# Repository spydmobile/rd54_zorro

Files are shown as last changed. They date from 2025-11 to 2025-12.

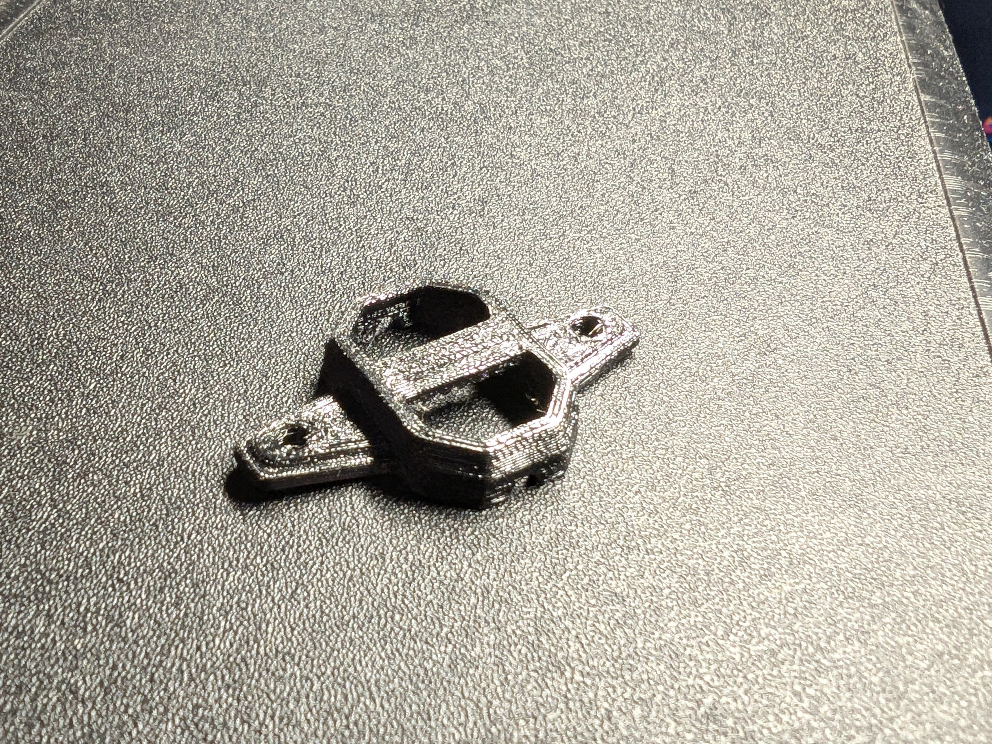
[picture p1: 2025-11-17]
custom_3d_printed_parts/RX mount/30.5 mm Receiver Holder (e.g. EP1, FlyFishRC VX3 style) - 7046298/images/PXL_20250523_1721312562.jpg

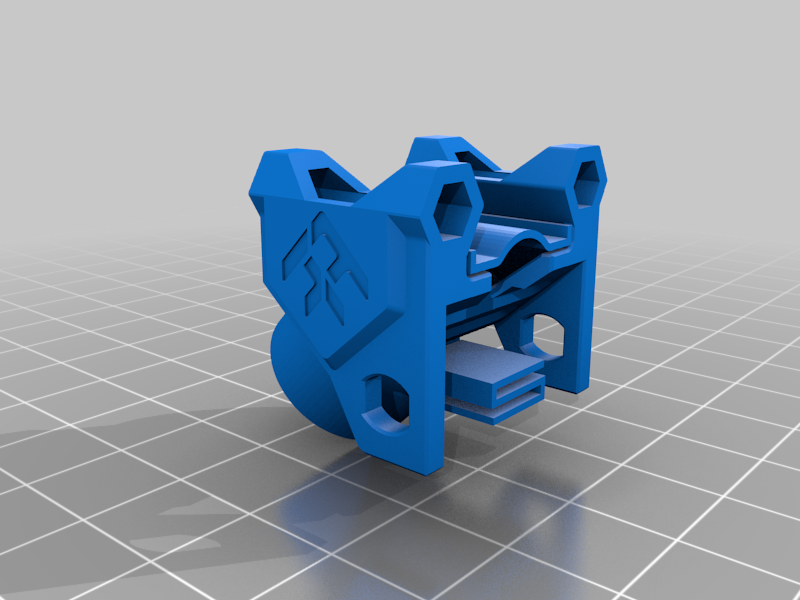
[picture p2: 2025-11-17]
custom_3d_printed_parts/factory_TPU_Parts/FlyFishRC Volador VX3 _ VX3.5 All-In-One TPU - 6052757/images/b86a3414-6690-473e-aafb-5c03349f377d.png

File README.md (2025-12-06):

# RD-54 "Zorro"

**Drone Designator**: RD-54
**Code Name**: Zorro
**Operator**: SpyD
**Platform**: 3.5" Digital FPV Cruiser

This repository serves as the source of truth for the RD-54 "Zorro" drone - a 3.5" digital FPV cruiser for exploration and cinematic HD video.

---

## Project Timeline

- **Parts Ordered**: Saturday, May 17, 2025 @ 8:56 AM
- **Build Commenced**: Monday, May 26, 2025 @ 4:33 PM
- **First Test Flight**: TBD
- **Status**: Assembly phase - VTX install + config remaining

---

## Current Configuration

- **Frame**: FlyFishRC Volador VX3.5
- **FC/ESC**: SpeedyBee F405 40A AIO (BlueJay)
- **Motors**: Emax ECO II 2004 3000KV (x4)
- **Video**: HDZero Freestyle V2 VTX + Camera
- **Antenna**: HDZero (rear mount)
- **Receiver**: HappyModel ExpressLRS EP1 Dual-TCXO
- **GPS**: GEPRC M10-DQ + VIFLY GPS-Mate
- **Batteries**: 2x GNB 880mAh 6S HV 160C (XT30)

---

## Documentation

Complete build documentation available in [`/Documentation`](/Documentation):

- **[As-Built Parts List](Documentation/RD-54_AsBuilt_Parts_List.md)** - Current aircraft configuration
- **[Build Timeline](Documentation/RD-54_Build_Timeline.md)** - Complete project history
- **[Incident Log](Documentation/RD-54_Incident_Log.md)** - Crash reports and maintenance
- **[Modifications Log](Documentation/RD-54_Modifications_Log.md)** - Engineering changes tracker

See [Documentation README](Documentation/README.md) for complete index.

---

## Quick Status

| Status | Value |
|---|---|
| Airworthy | No |
| Blocker | VTX install + Betaflight config |
| Total Flights | 0 |
| Total Incidents | 0 |

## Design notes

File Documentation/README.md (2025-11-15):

# RD-54 "Zorro" Documentation

**Aircraft Designator**: RD-54 (Code Name: Zorro)
**Operator**: SpyD (Franco Nogarin)
**Platform**: 3.5" Digital FPV Cruiser
**Primary Mission**: Exploration and cinematic FPV flights with HD digital video
**Last Updated**: November 14, 2025

---

## Quick Reference

### Current Status

| Attribute | Value |
|---|---|
| **Build Status** | Assembly Phase (~70% complete) |
| **Airworthiness** | Not Yet Airworthy (under construction) |
| **Flight Hours** | 0.0 |
| **Total Incidents** | 0 |
| **Total Modifications** | 1 (MOD-001: GPS Stack) |
| **Configuration** | Original Build Spec + GPS Stack Enhancement |
| **Mission Profile** | Digital FPV Cruiser |
| **Latest Milestone** | Motor wiring complete (Nov 14, 2025) |

### Key Specifications

| Component | Current Configuration |
|---|---|
| **Frame** | FlyFishRC Volador VX3.5 (3.5") |
| **FC/ESC** | SpeedyBee F405 AIO 40A (3-6S) |
| **Motors** | Emax ECO II 2004 3000KV |
| **Props** | Gemfan Hurricane 3525-3 Tri-Blade |
| **VTX** | Walksnail Moonlight HD digital (LHCP) |
| **RX** | HappyModel ExpressLRS EP1 (long range) |
| **GPS** | GEPRC M10-DQ with DPS310 baro |
| **GPS-Mate** | VIFLY GPS-Mate (lost model recovery) |
| **GPS Mount** | Custom 3D printed TPU stack (MOD-001) |
| **Battery** | 2x GNB 880mAh 6S HV 160C XT30 |

---

## Documentation Structure

### Primary Documentation

#### 1. [RD-54_AsBuilt_Parts_List.md](RD-54_AsBuilt_Parts_List.md)
**Single source of truth for current aircraft configuration**

Contains:
- Complete parts list with status
- Current operational configuration
- Pending upgrades
- Known issues
- Maintenance log

**Update when**: Parts are changed, issues discovered, maintenance performed

---

#### 2. [RD-54_Incident_Log.md](RD-54_Incident_Log.md)
**Comprehensive crash reports and damage assessments**

Contains:
- Chronological incident reports
- Damage assessments
- Root cause analysis
- Repair actions
- Lessons learned

**Update when**: Any crash, incident, or damage occurs

---

#### 3. [RD-54_Modifications_Log.md](RD-54_Modifications_Log.md)
**Track all engineering changes from original specification**

Contains:
- Sequential modification records (MOD-XXX)
- Original vs modified configuration
- Rationale and justification
- Installation procedures
- Performance impact

**Update when**: Planning, installing, or completing any modification

---

#### 4. [RD-54_Build_Timeline.md](RD-54_Build_Timeline.md)
**Chronological project history and future planning**

Contains:
- Build phases and milestones
- Project statistics
- Lessons learned
- Future activities

**Update when**: Major milestones reached, planning future work

---

### Reference Materials

#### [spyd.com_RD-54_README.md](spyd.com_RD-54_README.md)
Original parts list from spyd.com site. Reference only.

---

## How to Use This Documentation

### For Operators (SpyD)
1. **After a crash**: Document in `RD-54_Incident_Log.md`
2. **Ordering parts**: Update `RD-54_AsBuilt_Parts_List.md` (mark as "pending")
3. **Installing upgrades**: Create entry in `RD-54_Modifications_Log.md`
4. **After installation**: Update parts list status to "operational"
5. **Major milestones**: Update `RD-54_Build_Timeline.md`

### For Future Claude Instances
1. Read `CLAUDE.md` in repository root (your instructions)
2. Read this README (navigation guide)
3. Check `RD-54_AsBuilt_Parts_List.md` for current config
4. Review recent incident and modification entries
5. Ask operator what needs documenting

### For Documentation Maintenance
- Keep all cross-references current
- Update "Last Updated" dates
- Maintain chronological integrity
- Preserve historical records
- Follow markdown formatting standards

---

## Documentation Standards

### Markdown Formatting
- Tables for component lists and comparisons
- `---` dividers between major sections
- `**bold**` for component names and key terms
- `[ ]` checkboxes for pending actions
- Dates in ISO format (YYYY-MM-DD) or full format

### Technical Accuracy
- Full part numbers and model names
- Vendor names and order dates
- Quantities and prices when available
- Specific pad/connector names
- Units for all measurements (voltage, power, frequency)

### Documentation Voice
- Clear, technical language
- Assume FPV drone knowledge
- Document for future troubleshooting
- Include warnings and critical notes
- Capture operator's rationale

---

## Current Focus Areas

**Mission Profile**: Digital FPV Cruiser - optimized for smooth exploration flights with HD digital video

**Build Progress**: Assembly phase ~70% complete (started May 26, 2025)
- ✓ Frame assembled
- ✓ All motors mounted and wired (4 of 4 - completed Nov 14, 2025)
- ✓ FC/ESC stack installed and positioned
- ✓ Custom GPS stack fabricated and wired (MOD-001)
- ⏳ Remaining: Install VTX/Camera/RX/buzzer, mount GPS stack (last), wire management

**Next Steps**:
- Install Walksnail Moonlight VTX/Camera (next major task)
- Install ExpressLRS receiver
- Install buzzer
- Wire management and antenna routing
- Mount GPS stack to frame (planned as final component)
- Install top plate
- Betaflight configuration (GPS Rescue, RTH enabled)
- Bench testing
- Maiden flight

**Key Features for Cruiser Mission**:
- Walksnail HD digital FPV for cinematic footage
- GPS Rescue and Return Home for extended range safety
- VIFLY GPS-Mate for lost model recovery
- ExpressLRS long-range control link

**Documentation Priorities**:
- Document build progress and assembly milestones
- Capture configuration decisions for cruiser-optimized setup
- Record any issues encountered

---

## Contact & Support

**Operator**: SpyD (Franco Nogarin)
**Archivist**: Claude Code, RD-54 SME
**Repository**: /Users/franconogarin/localcode/rd54_zorro

---

## Document History

- **v1.0** (Nov 14, 2025): Initial documentation structure created
  - Created primary documentation files
  - Established templates and standards
  - Populated with current build information

---

**Next Review Date**: After first flight or major milestone

**Archivist**: Claude Code, RD-54 SME

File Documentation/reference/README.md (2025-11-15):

# Reference Materials

This directory contains **reference-only** documentation - original planning documents and historical specifications that should **NOT** be modified.

---

## Contents

### [spyd.com_RD-54_README.md](spyd.com_RD-54_README.md)
Original parts list from spyd.com site.

**Purpose**: Historical reference for original build specification
**Status**: Reference only - DO NOT MODIFY
**Date**: May 2025 (original build planning)

Contains:
- Original parts selection
- Baseline component specifications
- Initial build intent

---

## Usage Notes

### Reference Materials Are:
- ✓ Historical records
- ✓ Original planning documents
- ✓ Comparison baselines
- ✓ Preserved in original form

### Reference Materials Are NOT:
- ✗ Current configuration (see `RD-54_AsBuilt_Parts_List.md`)
- ✗ Living documents
- ✗ To be modified or updated
- ✗ Sources of truth for current specs

---

## For Current Configuration

**Always refer to the primary documentation**:
- Current specs: `../RD-54_AsBuilt_Parts_List.md`
- Modifications: `../RD-54_Modifications_Log.md`
- Incidents: `../RD-54_Incident_Log.md`
- Timeline: `../RD-54_Build_Timeline.md`

---

## Future Reference Documents

As the project evolves, additional reference materials may be added here:
- Original vendor invoices/receipts
- Initial planning notes
- Alternative build proposals
- Retired specifications

All reference materials should be clearly dated and marked as historical.

---

**Last Updated**: November 14, 2025
**Archivist**: Claude Code, RD-54 SME

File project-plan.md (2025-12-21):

# Project Plan: RD54 Zorro

**Project:** RD54_Zorro
**Owner:** Circuit (Fleet Steward)
**Created:** December 21, 2025
**Status:** Under Construction (~70%)

---

## Overview

RD54 "Zorro" is a 3.5" digital FPV cruiser optimized for smooth exploration with HD video. Features Walksnail digital system, GPS Rescue, and long-range ELRS.

**Repository:** `spydmobile/RD54_Zorro`
**Location:** `projects/drone_management/drones/RD54_Zorro/`
**Platform:** 3.5" Digital Cruiser (FlyFishRC Volador VX3.5)

---

## Current State

| Attribute | Value |
|---|---|
| **Build Status** | Assembly Phase (~70%) |
| **Airworthiness** | NOT YET AIRWORTHY |
| **Flight Hours** | 0.0 |
| **Total Incidents** | 0 |
| **Video System** | Walksnail Moonlight HD (LHCP) |
| **Control Link** | ExpressLRS EP1 (pending install) |
| **GPS** | GEPRC M10-DQ + VIFLY GPS-Mate |

**Completed:**
- Frame assembled
- All 4 motors mounted and wired (Nov 14, 2025)
- FC/ESC stack installed
- Custom GPS stack fabricated (MOD-001)

**Remaining:**
- VTX/Camera installation
- Receiver installation
- Buzzer installation
- Wire management
- GPS stack mounting (final step)
- Betaflight configuration
- Maiden flight

---

## Milestones

### Milestone 1: Frame & Motors (COMPLETE)
**Status:** Complete | **Date:** November 14, 2025

- [x] Frame assembly (Volador VX3.5)
- [x] FC/ESC stack positioning
- [x] Motor 1 mounting and wiring
- [x] Motor 2 mounting and wiring
- [x] Motor 3 mounting and wiring
- [x] Motor 4 mounting and wiring

### Milestone 2: GPS Stack (COMPLETE)
**Status:** Complete | **Date:** November 2025

- [x] Design custom TPU stack mount (MOD-001)
- [x] 3D print GPS mount
- [x] Wire GPS and GPS-Mate
- [x] Test fit on frame

### Milestone 3: Video System (IN PROGRESS)
**Status:** In Progress | **Priority:** High

- [x] Parts acquired (Walksnail Moonlight HD)
- [ ] Mount VTX to frame
- [ ] Install camera
- [ ] Route antenna (LHCP)
- [ ] Wire to FC

### Milestone 4: Receiver & Buzzer (PENDING)
**Status:** Pending | **Priority:** High

- [ ] Install ExpressLRS EP1 receiver
- [ ] Route RX antennas
- [ ] Install buzzer (5V)
- [ ] Wire management

### Milestone 5: GPS Final Mount (PENDING)
**Status:** Pending | **Priority:** Medium

Install GPS stack as final component (on top).

- [ ] Mount GPS stack to frame
- [ ] Antenna placement optimization
- [ ] Install top plate

### Milestone 6: Configuration & Testing (PENDING)
**Status:** Pending | **Priority:** High

- [ ] Betaflight configuration
- [ ] GPS Rescue setup
- [ ] RTH configuration
- [ ] Walksnail binding
- [ ] ELRS binding
- [ ] Bench test all systems
- [ ] Pre-flight safety checks
- [ ] First hover test
- [ ] Maiden FPV flight

---

## GitHub Issues

| # | Title | Labels | Priority |
|---|---|---|---|
| 1 | Install HDZero Freestyle V2 VTX/Camera System | pending-install, video-system | high |
| 3 | Install ExpressLRS EP1 Receiver and Antennas | pending-install, radio-system | high |
| 4 | Install GPS/GPS-Mate Stack | pending-install | - |
| 5 | Install HDZero Antenna Holder | pending-install, video-system | - |
| 6 | Install XT60 Battery Mount | pending-install | - |

*Note: Issue #1 references HDZero but drone uses Walksnail - verify correct VTX*

---

## Current Tasks

| Task | Priority | Status |
|---|---|---|
| Install Walksnail VTX/Camera | High | Next task |
| Install ELRS receiver | High | After VTX |
| Install buzzer | Medium | After RX |
| Wire management | Medium | After components |
| Mount GPS stack | Medium | Last component |
| Betaflight configuration | High | After assembly |
| Maiden flight | High | Final milestone |

---

## Operations

**Build documentation:**
- Parts List: `Documentation/RD-54_AsBuilt_Parts_List.md`
- Timeline: `Documentation/RD-54_Build_Timeline.md`
- Modifications: `Documentation/RD-54_Modifications_Log.md`

**Mission profile:** Digital FPV Cruiser
- Smooth exploration with HD video
- GPS Rescue for extended range safety
- Return-to-home capability

---

*Circuit - Fleet Steward*

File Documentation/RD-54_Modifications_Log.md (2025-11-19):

# RD-54 "Zorro" - Modifications Log

**Aircraft Designator**: RD-54 (Code Name: Zorro)
**Operator**: SpyD (Franco Nogarin)
**Last Updated**: November 15, 2025

---

## Purpose

This log tracks all engineering changes and modifications to RD-54 "Zorro" from the original build specification. Each modification receives a sequential MOD number.

---

## Modification Summary

| MOD # | Date | Category | Component | Status | Impact |
|---|---|---|---|---|---|
| MOD-001 | Nov 2025 | Enhancement | GPS/GPS-Mate Stack | Completed | Added VIFLY GPS-Mate, improved GPS elevation |
| MOD-002 | Nov 15, 2025 | Replacement | VTX System | In Progress | Changed from Walksnail Moonlight to HDZero Freestyle V2 |

**Total Modifications**: 2
**Current Configuration**: Original Build Spec + GPS Stack Enhancement + HDZero VTX

---

## Modification Categories

- **Emergency Repair**: Forced by damage/incident
- **Upgrade**: Performance or reliability improvement
- **Enhancement**: New capability addition
- **Replacement**: Like-for-like part swap

---

## Modifications

### MOD-001 - Custom 3D Printed GPS/GPS-Mate Stack

**Date Proposed**: November 2025
**Date Implemented**: November 2025
**Category**: Enhancement
**Status**: Completed (ready for installation)

#### Original Configuration

| Component | Part Number | Specification |
|---|---|---|
| GPS | GEPRC M10-DQ | GPS/GNSS with DPS310 baro, front mount elevated 8mm+ |
| GPS-Mate | N/A | Not included in original build |
| GPS Mount | N/A | Standard elevation mount |

#### Modified Configuration

| Component | Part Number | Specification |
|---|---|---|
| GPS | GEPRC M10-DQ | GPS/GNSS with DPS310 baro, mounted on custom stack |
| GPS-Mate | VIFLY GPS-Mate | Lost-model finder, integrated into stack |
| GPS Mount | Custom 3D Printed (TPU) | Modular vertical stack design |

#### Rationale

**Technical Justification**:
- Elevates GPS module higher for improved signal reception and reduced interference from carbon fiber frame
- Integrates VIFLY GPS-Mate lost-model finder for aircraft recovery capability
- Modular design allows easy servicing/replacement of individual components
- TPU material provides vibration damping and impact resistance

**Performance Impact**:
- Expected: Better GPS lock performance with increased elevation
- Expected: Aircraft recovery capability via GPS-Mate beacon
- Expected: Reduced vibration-induced GPS noise

**Operator Notes**:
Lost-model recovery is critical for a small 3.5" platform that could be difficult to visually locate. Custom integrated stack solution is more elegant than separate mounting solutions.

#### Parts Required

| Part | Vendor | Order Date | Cost | Status |
|---|---|---|---|---|
| VIFLY GPS-Mate | TBD | TBD | TBD | ✓ Acquired |
| TPU Filament | TBD | TBD | TBD | ✓ Used |
| Custom 3D Printed Parts | In-house design/print | Nov 2025 | Material cost only | ✓ Completed |

#### Implementation Notes

**Design Date**: November 2025
**Print Date**: November 2025
**Wiring Completed**: November 19, 2025
**Installation Status**: Ready for installation (not yet mounted to aircraft)
**Designed/Built By**: SpyD

**Design Features**:
- Yellow TPU construction for visibility and flexibility
- Modular vertical stack configuration
- GPS module on top ("ANTENNA THIS SIDE UP" orientation)
- VIFLY GPS-Mate in middle section
- Custom wiring harness fabricated (5-pin JST + 2 I2C solder wires)
- Integrated mounting points for frame installation

**Custom Wiring Harness** (Completed November 19, 2025):
- **5-pin JST Connector** (FC → GPS-Mate):
  - Black = GND
  - White = TX (from FC) → RX (to GPS-Mate)
  - Green = RX (from FC) → TX (to GPS-Mate)
  - Red = 5V
  - Yellow = BZ- (buzzer negative from FC to GPS-Mate built-in buzzer)
- **I2C Solder Connections**:
  - Drone SDA wire (white) → solder to GPS-Mate SDA wire (green)
  - Drone SCL wire (blue) → solder to GPS-Mate SCL wire (blue)

**Buzzer Integration**:
- GPS-Mate has integrated buzzer service
- FC buzzer pads wired to GPS-Mate BZ- (yellow wire in 5-pin JST)
- Provides all buzzer functions: arming, battery warnings, lost model beacon, etc.
- **No external buzzer needed** - GPS-Mate handles all buzzer functionality

**Installation Procedure**:
1. Mount GPS stack to frame (install last after other components)
2. Plug 5-pin JST connector from drone harness into GPS-Mate
3. Solder drone SDA wire (white) to GPS-Mate SDA wire (green)
4. Solder drone SCL wire (blue) to GPS-Mate SCL wire (blue)
5. Verify all connections secure and insulated
6. Configure GPS in Betaflight

**Notes**:
Assembly has been fabricated, wired, and tested off-aircraft. Drone-side harness complete. Ready to install when frame wiring phase continues. See reference photo: `Documentation/reference/build-images/GPS_Stack.jpg`

#### Post-Modification Performance

**Test Flight Date**: TBD (aircraft not yet airworthy)
**Test Results**: TBD

**Expected vs Actual**: TBD after flight testing

#### Related Documents

- Incident: N/A
- Timeline: Updated in RD-54_Build_Timeline.md
- Parts List: Updated in RD-54_AsBuilt_Parts_List.md
- Reference Photo: `Documentation/reference/build-images/GPS_Stack.jpg`

---

### MOD-002 - VTX System Technology Change (Walksnail → HDZero)

**Date Proposed**: November 15, 2025
**Date Implemented**: In Progress
**Category**: Replacement
**Status**: In Progress

#### Original Configuration

| Component | Part Number | Specification |
|---|---|---|
| VTX | Walksnail Moonlight | Digital HD VTX, large footprint kit, JST-SH 4-pin power, LHCP pigtails |
| Camera | Walksnail Moonlight Camera | Integrated with VTX kit |
| Antennas | LHCP (included with kit) | Left-hand circular polarization |

#### Modified Configuration

| Component | Part Number | Specification |
|---|---|---|
| VTX | HDZero Freestyle V2 | Digital HD VTX (specifications TBD) |
| Camera | HDZero Freestyle V2 Camera | Integrated with VTX |
| Antennas | TBD | TBD |

#### Rationale

**Technical Justification**:
- Both systems are digital HD - technology swap with similar capabilities
- HDZero Freestyle V2 became available from mapping mission
- Installation ramifications similar between both digital systems
- Allows RD-54 to proceed while RD-59 timeline shifted

**Performance Impact**:
- Expected: Similar HD digital video performance
- Expected: Comparable latency and range characteristics
- Expected: Similar installation footprint and wiring requirements

**Operator Notes**:
RD-59 project timeline changed and won't be airworthy for a while. HDZero Freestyle V2 showed up from yesterday's mapping mission, making it available for RD-54 instead. Since both are digital systems, the install approach should be comparable.

#### Parts Required

| Part | Vendor | Order Date | Cost | Status |
|---|---|---|---|---|
| HDZero Freestyle V2 VTX/Camera | From mapping mission | N/A | N/A | ✓ Available |
| Walksnail Moonlight (original) | - | May 17, 2025 | - | ⏳ Reassigned to other aircraft |

#### Installation Procedure

- [ ] Design and print any required camera/VTX mounts
- [ ] Mount HDZero Freestyle V2 VTX to frame
- [ ] Mount HDZero camera
- [ ] Wire VTX power to FC (verify voltage requirements)
- [ ] Wire VTX data connections (if applicable)
- [ ] Route antenna(s)
- [ ] Bench test video system
- [ ] Flight test video quality

#### Implementation Notes

**Installation Date**: TBD (in progress)
**Installed By**: SpyD

**Notes**:
Modification identified on November 15, 2025 after arm covers were completed. HDZero system will be installed after antenna mounts are designed/printed and ExpressLRS receiver is installed.

#### Post-Modification Performance

**Test Flight Date**: TBD
**Test Results**: TBD

**Expected vs Actual**: TBD

#### Related Documents

- Incident: N/A
- Timeline: Updated in RD-54_Build_Timeline.md (November 15, 2025)
- Parts List: Updated in RD-54_AsBuilt_Parts_List.md

---

## Modification Template

When documenting a modification, use this template:

### MOD-XXX - [Brief Description]

**Date Proposed**: [Date]
**Date Implemented**: [Date]
**Category**: [Emergency Repair / Upgrade / Enhancement / Replacement]
**Status**: [Proposed / In Progress / Completed / Abandoned]

#### Original Configuration

| Component | Part Number | Specification |
|---|---|---|
| | | |

#### Modified Configuration

| Component | Part Number | Specification |
|---|---|---|
| | | |

#### Rationale

**Technical Justification**:
[Why this modification is being made]

**Performance Impact**:
[Expected performance changes]

**Operator Notes**:
[Operator's reasoning/decision factors]

#### Parts Required

| Part | Vendor | Order Date | Cost | Status |
|---|---|---|---|---|
| | | | | |

#### Installation Procedure

- [ ] [Step 1]
- [ ] [Step 2]
- [ ] [Bench test]
- [ ] [Flight test]

#### Implementation Notes

**Installation Date**: [Date]
**Installed By**: SpyD

**Notes**:
[Any installation observations]

#### Post-Modification Performance

**Test Flight Date**: [Date]
**Test Results**:
[Performance observations]

**Expected vs Actual**:
[Did it meet expectations?]

#### Related Documents

- Incident: [Link to incident if applicable]
- Timeline: [Link to timeline entry]
- Parts List: [Updated in RD-54_AsBuilt_Parts_List.md]

---

**Document Version**: 1.0
**Archivist**: Claude Code, RD-54 SME

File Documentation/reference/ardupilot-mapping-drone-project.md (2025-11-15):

# ArduPilot Mapping Drone with ELRS MAVLink Telemetry
## Cable-Free Ground Control Station Setup

**Project Goal:** Build a custom autonomous mapping drone using ArduPilot with wireless MAVLink telemetry over ExpressLRS, eliminating the need for separate telemetry radios or cables between transmitter and laptop.

**Primary Use Case:** Aerial mapping and surveying for forestry/wildfire management applications

---

## System Architecture Overview

```
┌─────────────────────────────────────────────────────────┐
│                      AIRCRAFT                            │
│                                                          │
│  ┌─────────────────────────────────────────────────┐   │
│  │ Flywoo GOKU H743 PRO Mini Stack                  │   │
│  │ - H743 Flight Controller                         │   │
│  │ - 45A AM32 ESC (integrated)                      │   │
│  │ - ArduPilot Firmware                             │   │
│  │ - MAVLink configured on UART                     │   │
│  └──────────────┬──────────────────────────────────┘   │
│                 │                                        │
│                 │ UART Connection                        │
│                 │                                        │
│  ┌──────────────▼──────────────────────────────────┐   │
│  │ iFlight ELRS 2.4GHz 500mW TX Module              │   │
│  │ (Flashed with RECEIVER firmware)                 │   │
│  │ - RX-as-TX mode (ELRS 3.5+)                      │   │
│  │ - 500mW uplink power                             │   │
│  │ - MAVLink protocol mode                          │   │
│  └─────────────────────────────────────────────────┘   │
│                                                          │
└──────────────────────────┬───────────────────────────────┘
                           │
                           │ RF Link (2.4GHz ELRS)
                           │ • RC Control (uplink)
                           │ • MAVLink Telemetry (bidirectional)
                           │
┌──────────────────────────▼───────────────────────────────┐
│                   GROUND STATION                          │
│                                                           │
│  ┌────────────────────────────────────────────────┐     │
│  │ RadioMaster Boxer Transmitter                   │     │
│  │                                                 │     │
│  │  ┌──────────────────────────────────────────┐ │     │
│  │  │ Ranger Micro 2.4GHz ELRS TX Module       │ │     │
│  │  │ - 1W output power                        │ │     │
│  │  │ - WiFi Backpack enabled                  │ │     │
│  │  │ - MAVLink mode                           │ │     │
│  │  │ - Creates WiFi AP                        │ │     │
│  │  └─────────────┬────────────────────────────┘ │     │
│  │                │                                │     │
│  │                │ WiFi UDP (MAVLink)             │     │
│  └────────────────┼────────────────────────────────┘     │
│                   │                                       │
│                   │ Wireless Connection                   │
│                   │ No cables!                            │
│  ┌────────────────▼────────────────────────────────┐    │
│  │ Laptop / Tablet                                  │    │
│  │ - Mission Planner / QGroundControl               │    │
│  │ - Connects to "ExpressLRS TX Backpack XXXXXX"   │    │
│  │ - UDP port 14550                                 │    │
│  └──────────────────────────────────────────────────┘    │
│                                                           │
└───────────────────────────────────────────────────────────┘
```

---

## Hardware Bill of Materials

### Aircraft Components

| Item | Model | Purpose | Price | Notes |
|---|---|---|---|---|
| **Flight Controller Stack** | Flywoo GOKU H743 PRO Mini 45A AM32 20x20 | Flight control + ESC | $114.99 | H743 processor, 20x20 mounting, integrated 45A ESC |
| **ELRS TX Module** | iFlight ELRS 2.4GHz 500mW TX | Telemetry (flashed as RX) | ~$42.00 | Will be flashed with receiver firmware using RX-as-TX feature |
| **GPS Module** | Standard ArduPilot-compatible GPS | Position/navigation | ~$30-80 | UBLOX M8N/M9N or better |
| **Frame** | Your choice | Airframe | Varies | Based on your mapping mission requirements |
| **Motors** | Your choice | Propulsion | Varies | Match to frame and battery |
| **Battery** | LiPo 4S-6S | Power | Varies | Based on flight time requirements |

### Ground Station Components

| Item | Model | Purpose | Price | Status |
|---|---|---|---|---|
| **Transmitter** | RadioMaster Boxer 4-in-1 | RC control | - | ✅ You own this |
| **ELRS TX Module** | Ranger Micro 2.4GHz ELRS | 1W transmitter with WiFi | - | ✅ You own this |
| **Laptop/Tablet** | Your existing device | Ground control station | - | ✅ You own this |

### Additional Requirements

- **Antenna for aircraft ELRS TX:** Standard dipole or directional (comes with module)
- **Power wiring:** For connecting ELRS module to flight controller power
- **Mission Planner or QGroundControl** (free software)

**Total New Hardware Cost:** ~$157 (FC stack + ELRS TX module for aircraft)

---

## Software & Firmware Requirements

### Aircraft Side

1. **ArduPilot Firmware**
   - Version: Latest stable (4.5.x or newer)
   - Target: FlywooH743PRO or similar H743 target
   - Download: https://firmware.ardupilot.org/

2. **ELRS Firmware for TX Module**
   - Version: 3.5.0 or newer (required for RX-as-TX feature)
   - Configuration: Receiver firmware flashed to TX module
   - Tool: ExpressLRS Configurator

### Ground Station Side

1. **ELRS Firmware for Ranger Micro**
   - Version: 3.5.0 or newer
   - Configuration: MAVLink mode enabled
   - WiFi backpack enabled

2. **EdgeTX or OpenTX** (already on Boxer)
   - ELRS Lua script (latest version)

3. **Ground Control Station Software**
   - Mission Planner (Windows) or
   - QGroundControl (Windows/Mac/Linux/Android/iOS)

---

## Setup Process

### Phase 1: Flash & Configure Aircraft ELRS TX Module

This is the clever part - flashing a TX module with receiver firmware to get 500mW uplink power.

#### Step 1.1: Flash iFlight TX Module with Receiver Firmware

1. **Install ExpressLRS Configurator 3.5+**
   - Download from: https://github.com/ExpressLRS/ExpressLRS-Configurator/releases

2. **Connect iFlight ELRS TX module via USB**

3. **In Configurator:**
   - Select Device Category: `2.4 GHz`
   - Select Device: Find the iFlight TX model
   - **Enable "RX as TX" option** in advanced settings
   - Set your binding phrase (must match ground TX)
   - Select Regulatory Domain: `ISM_2400` (FCC) or `EU_CE_2400` (EU)

4. **Build & Flash**
   - Click "Build & Flash"
   - Wait for completion
   - Module now acts as a high-power receiver

#### Step 1.2: Physical Installation on Aircraft

1. **Mount ELRS module** near the flight controller
2. **Connect power:**
   - 5V from flight controller BEC
   - GND to flight controller ground
3. **Connect UART:**
   - ELRS TX → Flight Controller RX (e.g., SERIAL2_RX)
   - ELRS RX → Flight Controller TX (e.g., SERIAL2_TX)
4. **Connect antenna** to ELRS module (critical - don't power without antenna!)

---

### Phase 2: Configure Flight Controller

#### Step 2.1: Flash ArduPilot Firmware

1. **Connect flight controller via USB**
2. **Open Mission Planner**
3. **Flash firmware:**
   - Setup → Install Firmware
   - Select "Copter" (or Plane/Rover based on your frame)
   - Choose latest stable version
   - Wait for flash completion

#### Step 2.2: Configure UART for MAVLink

Using Mission Planner, set these parameters:

```
# Configure SERIAL2 for MAVLink (adjust SERIAL number based on your wiring)
SERIAL2_PROTOCOL = 2         # MAVLink2
SERIAL2_BAUD = 460800       # 460800 baud (required for ELRS MAVLink)

# Configure RSSI from ELRS
RSSI_TYPE = 5               # ReceiverProtocol (gets RSSI from MAVLink RC)

# Other important parameters
RC_OPTIONS = 8192           # Bit 13: Enable 420KBaud for ELRS (if needed)
```

**Write Parameters** and **Reboot** the flight controller.

---

### Phase 3: Configure Ground Station ELRS (Ranger Micro)

#### Step 3.1: Update Ranger Micro Firmware

1. **Power on Boxer with Ranger Micro installed**
2. **Enable WiFi on Ranger Micro:**
   - Via Lua script: `WiFi Connectivity → Enable WiFi`
   - Or via 5-way button if your module has one

3. **Connect to WiFi:**
   - SSID: `ExpressLRS TX`
   - Password: `expresslrs`

4. **Open web browser → http://10.0.0.1**

5. **Flash Latest Firmware:**
   - Download latest ELRS 3.5.x firmware
   - Upload via web UI
   - Set binding phrase (must match aircraft)
   - Flash firmware

#### Step 3.2: Configure for MAVLink Mode

Using EdgeTX/OpenTX on your Boxer:

1. **Access ELRS Lua Script:**
   - Long press SYS on Boxer
   - Navigate to ExpressLRS script

2. **Configure Link Settings:**
   - Select `Other Devices` → Your aircraft receiver
   - Set `Serial Protocol` to **MAVLink**
   - Back to main menu
   - Set `Link Mode` to **MAVLink** (not Normal)
   
3. **Configure Performance Settings:**
   - `Packet Rate`: F1000 or 333Hz Full (recommended for MAVLink)
   - `TX Power`: 1000mW (1W)
   - `Telemetry Ratio`: Will auto-set to 1:2 in MAVLink mode

4. **Enable WiFi Telemetry Forwarding:**
   - In Lua script: `Backpack` menu
   - Set `Telemetry` to **WiFi**
   - Ranger Micro will now forward MAVLink via WiFi

---

### Phase 4: Connect Ground Control Station

#### Step 4.1: Connect Laptop to Ranger Micro WiFi

1. **On your laptop, connect to WiFi:**
   - SSID: `ExpressLRS TX Backpack XXXXXX`
   - Password: `expresslrs`

2. **Alternative (Home WiFi):**
   - You can configure the backpack to connect to your home WiFi
   - More convenient if you're always flying from same location

#### Step 4.2: Configure Mission Planner

1. **Open Mission Planner**

2. **Set Connection Type:**
   - Top right corner: Select `UDP`
   - Port: `14550` (default)

3. **Click "Connect"**

4. **Mission Planner should:**
   - Connect automatically
   - Start downloading parameters
   - Display telemetry data
   - Show aircraft position (once GPS lock)

#### Step 4.3: Verify Everything Works

**Test RC Control:**
- Move sticks on Boxer → Should see response in Mission Planner
- Flight Mode switch → Should change modes in Mission Planner

**Test Telemetry:**
- Should see GPS data
- Battery voltage
- RSSI/Link quality
- All MAVLink telemetry

**Test Parameter Changes:**
- Try changing a parameter in Mission Planner
- Should write successfully to aircraft

---

## Expected Performance

### Link Performance (2.4GHz ELRS)

| Packet Rate | Data Rate | Latency | Recommended Use |
|---|---|---|---|
| **F1000Hz** | ~4000 bps | ~4ms | Parameter download, mission upload, mapping |
| **333Hz Full** | ~3500 bps | ~6ms | Good balance, recommended for mapping |
| **250Hz** | ~2500 bps | ~8ms | Longer range, good telemetry |
| **150Hz** | ~1500 bps | ~12ms | Extended range missions |

### Power Budget

**Aircraft Side:**
- ELRS TX at 500mW: ~2.5W power draw
- Uplink range: 10-30 km (depending on conditions)

**Ground Side:**
- Ranger Micro at 1W: ~5-7W power draw
- Downlink range: 30+ km

**Your bottleneck:** Aircraft's 500mW uplink (not the ground 1W downlink)

### Practical Range Expectations

For **mapping missions:**
- **Conservative range:** 5-10 km
- **Typical operating range:** 3-5 km
- **Line of sight required:** Yes (for safe mapping operations)

This is **more than adequate** for:
- Forestry surveying
- Wildfire damage assessment
- Terrain mapping
- Area reconnaissance

---

## Mission Planning for Mapping

### Mission Planner Workflow

1. **Create Survey Mission:**
   - Mission Planner → Flight Plan tab
   - Draw polygon around area to map
   - Auto WP → Survey (Grid)
   - Set altitude, overlap percentage, camera trigger
   - Upload mission via MAVLink

2. **Pre-Flight Checks:**
   - GPS lock (3D fix)
   - HDOP < 2.0
   - Battery voltage good
   - RC link solid (check RSSI)
   - MAVLink telemetry flowing

3. **Execute Mission:**
   - Arm in stabilize/loiter
   - Switch to Auto mode
   - Aircraft executes survey grid
   - Monitor progress in Mission Planner

4. **Data Collection:**
   - Camera triggers at waypoints
   - Telemetry logs saved (for georeferencing)
   - Return to home when complete

### Integration with Your Workflow

Since you work with:
- **Wildfire management** (Prometheus fire modeling)
- **Forest planning**
- **WebODM** (drone mapping)
- **Geospatial applications**

This setup gives you:
- ✅ Full autonomous waypoint missions
- ✅ Real-time telemetry monitoring
- ✅ Parameter adjustment in-flight
- ✅ Precise GPS logging for georeferencing
- ✅ No cables between transmitter and laptop
- ✅ Professional-grade flight control

---

## Advantages of This Setup

### vs. Traditional SiK/RFD900 Telemetry Radio:

| Feature | This Setup | Traditional Radio |
|---|---|---|
| **Hardware cost** | $157 (reuses ELRS) | $200-400 (separate radios) |
| **Cables** | None (WiFi) | USB cable to laptop |
| **Dongles on laptop** | None | Telemetry radio required |
| **Complexity** | One RF link | Two separate links (RC + telem) |
| **Latency** | Very low (~4-8ms) | Higher (~50-100ms) |
| **Data rate at range** | Good (~2-4 kbps) | Similar |

### vs. Basic CRSF Telemetry:

- ✅ **Full MAVLink support** (not just basic telemetry)
- ✅ **Mission uploads** possible
- ✅ **Parameter changes** in field
- ✅ **Ground control station integration**
- ✅ **Professional workflow**

---

## Troubleshooting Guide

### Aircraft won't bind

**Check:**
- Binding phrase matches between TX and RX
- Both using same ELRS firmware version (3.5+)
- RX is actually flashed with receiver firmware
- Power and antenna connected properly

### No MAVLink telemetry

**Check:**
- `SERIAL2_PROTOCOL = 2` (MAVLink2)
- `SERIAL2_BAUD = 460800`
- TX/RX wires not swapped
- Link Mode set to **MAVLink** (not Normal) in Lua script
- Backpack telemetry set to **WiFi**

### Can't connect Mission Planner

**Check:**
- Connected to correct WiFi network
- UDP port 14550
- Aircraft powered and bound to TX
- MAVLink flowing from aircraft (check Lua script telemetry)

### Range is poor

**Check:**
- Antennas properly connected (especially aircraft)
- Antenna orientation (dipoles should be perpendicular)
- RF environment (interference, obstacles)
- Packet rate (lower = longer range)
- TX power settings

---

## Safety Notes

### Pre-Flight

- ✅ GPS 3D lock with good HDOP
- ✅ Compass calibrated
- ✅ Accelerometer calibrated  
- ✅ RC failsafe configured (RTH or Land)
- ✅ Battery voltage adequate
- ✅ Geofence configured (optional but recommended)
- ✅ Mission validated in simulator first

### In-Flight

- ⚠️ Maintain visual line of sight (regulations)
- ⚠️ Monitor RSSI/LQ (don't fly to edge of range)
- ⚠️ Always have RC override ready
- ⚠️ Monitor battery voltage
- ⚠️ Weather conditions appropriate

### Legal Compliance

- 📋 Follow Transport Canada drone regulations (Canada)
- 📋 Advanced operations certificate if required
- 📋 Maintain required documentation
- 📋 Respect airspace restrictions
- 📋 Privacy considerations for mapping

---

## Future Upgrades

### Optional Enhancements

1. **900MHz ELRS for extended range**
   - Dual-band LR1121 modules
   - 10-50+ km practical range
   - Better obstacle penetration

2. **Directional antenna on ground**
   - MOXON or patch antenna
   - Antenna tracker (auto-points at aircraft)
   - Significantly extends range

3. **Companion computer**
   - Raspberry Pi or similar
   - AI/computer vision for advanced missions
   - Real-time image processing

4. **RTK GPS**
   - Centimeter-level accuracy
   - Professional surveying grade
   - Integration with base station

---

## Resources

### Documentation

- **ArduPilot Wiki:** https://ardupilot.org/
- **ExpressLRS Docs:** https://www.expresslrs.org/
- **Mission Planner:** https://ardupilot.org/planner/
- **Flywoo Products:** https://flywoo.net/

### Communities

- **ArduPilot Discourse:** https://discuss.ardupilot.org/
- **ExpressLRS Discord:** https://discord.gg/expresslrs
- **Mission Planner Support:** ArduPilot forums

### Your Background Resources

- **WebODM:** For processing mapping imagery
- **QGIS:** For geospatial analysis
- **Your existing forestry/wildfire tools**

---

## Project Summary

**You're building:** A professional autonomous mapping drone with wireless telemetry

**Total new hardware cost:** ~$157 (FC + aircraft ELRS module)

**Key innovation:** Using Josh Bardwell's WiFi backpack technique eliminates all cables and separate telemetry hardware while maintaining professional capabilities

**Result:** A clean, cable-free ground station with full MAVLink telemetry for autonomous mapping missions in support of forestry management and wildfire applications.

---

**Questions or need clarification on any steps? This is a comprehensive build but very achievable given your 12+ years of UAV experience!**

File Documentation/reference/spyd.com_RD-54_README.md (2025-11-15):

		Frame: FlyFishRC Volador VX3.5 (X-config, 3.5”)
		FC / ESC: SpeedyBee F405 AIO 40A BlueJay (3–6 S)
		Motors: Emax ECO II 2004 3000 KV
		Props: Gemfan Hurricane 3525-3 Tri-Blade (2 CW + 2 CCW) — clear or black if you want props to be least visible on FPV footage
		VTX: Walksnail Moonlight (Moonlight kit — large footprint) — uses JST-SH 4-pin power plug; LHCP pigtails included
		RX: HappyModel ExpressLRS EP1 Dual-TCXO (dual antenna diversity)
		GPS / GNSS: GEPRC M10-DQ (with DPS310 baro) — front mount elevated by 8 mm (or taller if obstructed)
		Buzzer: 5 V Std buzzer (mounted near top plate)
    2 x GNB8806S160AHV	GNB 880mAh 6S HV - 160C - XT30

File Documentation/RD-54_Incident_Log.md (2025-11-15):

# RD-54 "Zorro" - Incident Log

**Aircraft Designator**: RD-54 (Code Name: Zorro)
**Operator**: SpyD (Franco Nogarin)
**Last Updated**: November 14, 2025

---

## Purpose

This log documents all crashes, incidents, and damage assessments for RD-54 "Zorro". Each incident receives a sequential number and follows a standardized reporting format.

---

## Incident Summary

| Incident # | Date | Location | Type | Status | Airworthy |
|---|---|---|---|---|---|
| - | - | - | - | - | - |

**Total Incidents**: 0
**Total Crashes**: 0
**Current Status**: Pre-flight (no incidents recorded)

---

## Incident Reports

No incidents have been recorded yet. RD-54 "Zorro" is still under construction and has not yet flown.

---

## Incident Report Template

When documenting an incident, use this template:

### Incident #XXX - [Brief Description]

**Date**: [Date]
**Time**: [Time]
**Location**: [Location/Flying Site]
**Flight Conditions**: [Weather, wind, visibility]
**Other Pilots/Aircraft**: [Who else was flying]
**Flight Phase**: [Takeoff/cruise/freestyle/landing/etc.]

#### Incident Description

[Detailed description of what happened]

#### Damage Assessment

| Component | Status | Damage Description | Action Required |
|---|---|---|---|
| | | | |

**Overall Assessment**: [Airworthy / Not Airworthy / Unknown]

#### Root Cause Analysis

**Probable Cause**: [Analysis of why incident occurred]

**Contributing Factors**:
- [Factor 1]
- [Factor 2]

#### Repair Actions

**Immediate Actions**:
- [ ] [Action item]

**Parts Ordered**:
| Part | Vendor | Order Date | ETA | Cost |
|---|---|---|-----|---|
| | | | | |

**Repairs Completed**:
- [ ] [Repair action]
- [ ] Post-repair testing

#### Lessons Learned

[What was learned from this incident]

#### Follow-Up

**Return to Service Date**: [Date]
**Post-Repair Test Flight**: [Date and results]

---

**Document Version**: 1.0
**Archivist**: Claude Code, RD-54 SME

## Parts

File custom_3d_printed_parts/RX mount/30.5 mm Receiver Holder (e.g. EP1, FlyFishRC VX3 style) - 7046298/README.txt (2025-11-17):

30.5 mm Receiver Holder (e.g. EP1, FlyFishRC VX3 style) by lasa01 on Thingiverse: https://www.thingiverse.com/thing:7046298

Summary:
Modified FlyFishRC VX3 Receiver Holder STL, with 30.5 mm hole spacing instead of 20 mm, and 3 mm holes instead of 2 mm. Print in TPU. Fits Happymodel EP1 receiver for example.

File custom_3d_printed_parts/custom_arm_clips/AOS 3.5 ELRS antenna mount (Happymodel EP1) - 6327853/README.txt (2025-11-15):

AOS 3.5 ELRS antenna mount (Happymodel EP1) by nuggetfpv on Thingiverse: https://www.thingiverse.com/thing:6327853

Summary:
Happymodel EP1 2.4g ELRS antenna mount for the AOS 3.5 frame. 4mm height at the standoff mounts, gives enough clearance for the VTX antenna mount.Print with TPU, 25% infill, 5 perimeters.Bend the two halves of the mount, then bend the antenna wires towards the mount. Insert both wires into the mount, then place the T joint of the antenna into the mount.

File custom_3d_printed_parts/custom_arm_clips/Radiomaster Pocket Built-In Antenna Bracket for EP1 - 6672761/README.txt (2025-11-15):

Radiomaster Pocket Built-In Antenna Bracket for EP1 by ya-mrgrey on Thingiverse: https://www.thingiverse.com/thing:6672761

Summary:
Remix of the Radiomaster Pocket internal antenna bracket ( https://www.thingiverse.com/thing:6568363) for the new design of Happymodel EP1 antenna.Original design works well for the older style Happymodel EP1 antenna, but it looks like Happymodel updated their EP1 to have larger plastic central piece and wider antenna arms (see photo).Newer antenna design doesn't fit into the bracket because of its thicker arms. This is a simple remix with wider channels for antenna arms, so the new EP1 fits.

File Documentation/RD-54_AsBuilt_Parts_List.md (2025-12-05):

# RD-54 "Zorro" - As-Built Parts List

**Aircraft Designator**: RD-54 (Code Name: Zorro)
**Operator**: SpyD (Franco Nogarin)
**Platform Type**: 3.5" Digital FPV Cruiser
**Primary Mission**: Exploration and cinematic FPV flights with HD digital video
**Current Status**: Under Construction - Assembly Phase
**Airworthiness**: Not Yet Airworthy
**Last Updated**: November 15, 2025

---

## Mission Profile

**Digital FPV Cruiser** - Optimized for smooth exploration and HD video capture

**Primary Uses**:
- Cruising and exploring interesting locations
- Recording cinematic HD footage via Walksnail digital FPV
- GPS-assisted flights with Return Home and GPS Rescue
- Small form factor for flying in tighter spaces
- Lost model recovery capability (VIFLY GPS-Mate)

**Flight Characteristics**:
- Flight time: 8-12 minutes (cruising)
- Range: Extended with ExpressLRS long-range control
- Video system: Walksnail Moonlight HD digital FPV
- Safety: GPS features + lost model beacon

**NOT Designed For**:
- Racing (not optimized for speed)
- Aggressive freestyle (can do some, but not primary mission)
- Autonomous mapping (Betaflight, not ArduPilot)
- Heavy payload carrying

---

## Current Configuration

### Airframe

| Component | Part Number/Model | Quantity | Status | Notes |
|---|---|---|---|---|
| **Frame** | FlyFishRC Volador VX3.5 | 1 | ✓ Assembled | X-config, 3.5" wheelbase |
| **Feet - All 4** | Custom 3D Printed (TPU) | 4 | ✓ Installed | Tall screw-mounted style, doubled height, ~15mm ground clearance, even stance, remixed from factory parts (6052757) |
| **Arm Covers - Front** | Custom 3D Printed (TPU) | 2 | ✓ V4 Installed | Bambu TPU, V4 design, remixed from Chimera 90mm |
| **Arm Covers - Rear** | Custom 3D Printed (TPU) | 2 | ✓ V5 Installed | Bambu TPU, 0.12mm HQ, V5 with integrated V2.0 antenna clips |
| **Antenna Clips** | Integrated into V5 Rear Covers | 2 | ✓ Installed | V2.0 design: bigger body with T-leg slot, strong retention, shim-mounted to one side |
| **Side Panels (Stack Protectors)** | Custom 3D Printed (TPU) | 2 | ✓ Installed | "RD-54 ZORRO" embossed, FC/ESC protection, remixed from than.gs/m/1260429, minor cleanup needed |
| **EP1 RX Holder** | Custom 3D Printed (TPU) | 1 | ✓ Installed | V6 design successful: MakerWorld holder + factory mounting flanges, underside mount, 0.12mm HQ, works as planned |
| **HDZero Antenna Holder** | Custom 3D Printed (TPU) | 1 | ✓ Printed | Bambu TPU, 0.12mm HQ, rear mount, source: makerworld.com/en/models/1769720, not yet installed |
| **XT60 Mount** | Custom 3D Printed (TPU) | 1 | ✓ Printed | Bambu TPU, 0.12mm HQ, rear standoff mount, source: makerworld.com/en/models/1203681 (XT30 design used for XT60), not yet installed |
| **GPS Mount** | Custom 3D Printed (TPU) | 1 | ✓ Fabricated (ready to install) | Yellow TPU, modular stack design - see MOD-001 |
| **Front Bumper/Camera Mount** | Custom 3D Printed (TPU) | 1 | ✓ Installed | Yellow TPU, 0.16mm HQ, tree supports, 5% gyroid infill, remixed from MakerWorld 1791670, smooth leading edge (no sawtooth), lightweight design, 19mm camera mount, HDZero Nano 90 test fit confirmed |

---

### Flight Control & Power

| Component | Part Number/Model | Quantity | Status | Notes |
|---|---|---|---|---|
| **FC/ESC Stack** | SpeedyBee F405 AIO 40A BlueJay | 1 | ✓ Installed and wired | 3-6S rating, integrated 40A ESC |
| **Motors** | Emax ECO II 2004 3000KV | 4 | ✓ Mounted and wired | All 4 motors soldered to AIO (completed Nov 14, 2025) |
| **Propellers** | Gemfan Hurricane 3525-3 Tri-Blade | 2 CW + 2 CCW | ✓ Available | Bright green installed for assembly photos |

---

### Power System

| Component | Part Number/Model | Quantity | Status | Notes |
|---|---|---|---|---|
| **Battery #1** | GNB 880mAh 6S HV 160C XT30 | 1 | ✓ Available | GNB8806S160AHV |
| **Battery #2** | GNB 880mAh 6S HV 160C XT30 | 1 | ✓ Available | GNB8806S160AHV |
| **Connector Type** | XT30 | - | ✓ Installed | Battery/aircraft interface on FC |
| **9V BEC** | External BEC Module (included with FC) | 1 | ✓ Installed | Modified to 9V output (soldered jumper per SpeedyBee instructions), tested at 9V, rated 2A @ 9V (sufficient for HDZero 15W/1.67A requirement), mounted in custom two-part protective enclosure on rear underside |
| **BEC Enclosure** | Custom 3D Printed (TPU) | 1 | ✓ Installed | Red TPU, 0.20mm Standard, 100% rectilinear infill, two-part screw-together design, fully encloses BEC, side wire exits, mounted to rear underside bottom plate, crash protection for underside impacts |

---

### Video System

| Component | Part Number/Model | Quantity | Status | Notes |
|---|---|---|---|---|
| **VTX** | HDZero Freestyle V2 | 1 | ✓ Test Fit Complete | Digital HD VTX, 3M tape mounting, clearances validated - see MOD-002 |
| **Camera** | HDZero Freestyle V2 Camera | 1 | ✓ Test Fit Complete | Front-mounted in aluminum cage (mini bando style for close-quarters flying) |
| **Original VTX** | ~~Walksnail Moonlight~~ | 1 | ⏳ Reassigned | Replaced by HDZero per MOD-002 |

---

### Radio System

| Component | Part Number/Model | Quantity | Status | Notes |
|---|---|---|---|---|
| **Receiver** | HappyModel ExpressLRS EP1 Dual-TCXO | 1 | ✓ Installed | Heat shrink applied, mounted in v6.4 RX holder, wired to FC UART6: Red(5V)→4V5, Black(GND)→G, Blue/Yellow(TX)→R6, Blue(RX)→T6 |
| **RX Holder** | Custom 3D Printed (TPU) | 1 | ✓ Installed | v6.4 design, improved fit, yellow TPU |
| **RX Antennas** | HappyModel EP1 Dual T-Antennas | 2 | ✓ Installed | ELRS antennas, mounted in V5 arm cover clips |

---

### Navigation & Sensors

| Component | Part Number/Model | Quantity | Status | Notes |
|---|---|---|---|---|
| **GPS/GNSS** | GEPRC M10-DQ | 1 | ✓ Wired (ready to install) | With DPS310 barometer, integrated into custom GPS stack (MOD-001), drone-side harness complete |
| **GPS-Mate** | VIFLY GPS-Mate | 1 | ✓ Wired (ready to install) | Lost-model finder beacon, integrated into custom GPS stack (MOD-001), drone-side harness complete |
| **GPS Wiring Harness** | Custom FC→GPS-Mate Harness | 1 | ✓ Fabricated | 5-pin JST (GND/TX/RX/5V/BZ-) + 2 I2C solder wires (SDA white, SCL blue), see MOD-001 for install procedure |

---

### Auxiliary Systems

| Component | Part Number/Model | Quantity | Status | Notes |
|---|---|---|---|---|
| **Buzzer** | Integrated in GPS-Mate | 1 | ✓ Wired | FC buzzer contacts wired to GPS-Mate BZ- (yellow wire in 5-pin JST), external buzzer not needed |

---

## Build History

### Initial Build (May 2025 - Present)

**Parts Ordered**: May 17, 2025
**Build Start**: May 26, 2025
**Build Status**: Assembly Phase - In Progress

**Current Progress**:
- ✓ Frame assembled
- ✓ Motors mounted to frame (all 4)
- ✓ All motors wired to AIO (4 of 4 complete - Nov 14, 2025)
- ✓ FC/ESC stack installed and positioned
- ✓ All 4 custom feet installed - tall screw-mounted configuration, even stance at ~15mm clearance (Nov 15, 2025)
- ✓ Custom arm covers installed (V4 on front arms, V5 with antenna clips on rear arms - Nov 15, 2025)
- ✓ Side panels (stack protectors) installed with RD-54 Zorro designation (Nov 15, 2025)
- ✓ EP1 RX holder V6 installed and working - mounted to underside frame (Nov 15, 2025)
- ✓ Custom GPS stack fabricated and wired (ready for installation - will be installed last)
- ✓ HDZero VTX/Camera test fit completed - clearances validated (Nov 15, 2025)
- ✓ Full assembly mockup validated - no collisions, wire routing visualized (Nov 15, 2025)
- ✓ Power requirement discovered - 6S HV too high for HDZero, 9V BEC solution identified (Nov 15, 2025)
- ✓ HDZero antenna holder printed (Nov 15, 2025)
- ✓ XT60 mount printed (Nov 15, 2025)
- ✓ GPS/GPS-Mate/FC custom wiring harness fabricated (Nov 19, 2025) - 5-pin JST + I2C solder wires
- ✓ BEC modified to 9V configuration (Nov 19, 2025) - soldered jumper, voltage tested and confirmed
- ⚠️ EP1 receiver needs heat shrink before installation
- ⏳ HDZero antenna holder installation (printed, ready to install)
- ⏳ XT60 mount installation (printed, ready to install)
- ⏳ 9V BEC mounting and wiring (modified to 9V ✓, will mount inline with VTX power cable, custom mount planned)
- ⏳ EP1 heat shrink and installation into mounted holder
- ⏳ HDZero VTX/Camera installation (test fit complete, awaiting 9V BEC and antenna holder)
- ⏳ Antennas ready to mount (clips installed, awaiting receiver installation)
- ✓ Buzzer integrated via GPS-Mate (FC buzzer pads wired to GPS-Mate BZ-)
- ⏳ GPS stack mounting (planned as final component)
- ⏳ Betaflight configuration not started
- ⏳ Radio binding not started

**Modifications from Original Spec**:
- **MOD-001**: Custom 3D printed TPU GPS/GPS-Mate stack (November 2025)
  - Added VIFLY GPS-Mate for lost-model recovery
  - Custom modular stack design for improved GPS elevation
  - See `RD-54_Modifications_Log.md` for details
- **MOD-002**: VTX system change (November 15, 2025)
  - Changed from Walksnail Moonlight to HDZero Freestyle V2
  - Both digital HD systems, similar install approach
  - RD-59 timeline shift made HDZero available from mapping mission
  - See `RD-54_Modifications_Log.md` for details

---

## Pending Upgrades/Changes

**Immediate Next Steps** (as of November 19, 2025):
- Modify BEC from 5V to 9V configuration
- Install HappyModel EP1 receiver (heat shrink first)
- Mount and route dual T-antennas to rear arm V5 clips
- Install HDZero Freestyle V2 VTX/Camera system (requires 9V BEC)
- Install HDZero antenna holder and XT60 mount
- Design/print additional underside protection (antenna clips need crash protection)
- Wire management and routing
- Mount GPS stack to frame (planned as final component)
- Install top plate
- Initial Betaflight configuration

---

## Known Issues

**Current Blockers**:
- VTX/Camera not installed (required for FPV operation) - BEC ready ✓
- Receiver not installed (required for control)
- No configuration or testing completed yet

**Recent Progress** (November 14, 2025):
- ✓ Motor wiring completed (all 4 motors soldered to AIO)
- ✓ FC/ESC stack positioned and mounted
- ✓ Solder pads cleaned with alcohol for clean connections

**Component Status**:
- Original ExpressLRS EP1 diverted to another aircraft (resolved - second EP1 located)

---

## Notes

- **Mission Focus**: Digital FPV Cruiser with Mini Bando style - smooth exploration and close-quarters flying with HD video
- **Video System**: HDZero Freestyle V2 digital HD FPV (changed from Walksnail per MOD-002)
- **Camera Setup**: Front-mounted in aluminum cage (mini bando style for close-quarters navigation and proximity flying)
- **Power Solution**: 9V BEC required for HDZero VTX (6S HV battery voltage too high for direct connection)
- **BEC Configuration**: External BEC modified to 9V output (soldered jumper per SpeedyBee instructions, tested and confirmed 9V)
- **BEC Mounting**: Inline with VTX power cable under top plate (custom 3D printed mount planned)
- **Power Path**: 6S HV Battery → VBAT → 9V BEC → HDZero VTX
- **Custom Parts**: TPU arm covers - V4 on front arms, V5 with integrated V2.0 antenna clips on rear arms (0.12mm HQ print)
- **Ground Clearance**: All 4 feet tall and screw-mounted at ~15mm clearance (initially 2 tall/2 short, upgraded for even stance)
- **RX Holder Success**: V6 design works as planned after 5 iterations (underside mount with hybrid design approach)
- **Antenna Retention**: V2.0 clips with T-leg slot design provide strong hold, won't release unless serious crash
- **Mounting Method**: HDZero VTX uses included 3M tape mounting (test fit validated, no clearance issues)
- **Custom Wiring**: GPS/GPS-Mate/FC require custom splice harness (JST connectors from each component)
- **GPS Mounting**: Custom TPU stack provides elevation and integrates VIFLY GPS-Mate (MOD-001)
- **Buzzer Integration**: GPS-Mate provides all buzzer functionality via FC buzzer pads (BZ- yellow wire), no external buzzer needed
- **3D Print Sources**: Mix of remixed designs (arm covers, side panels, RX holder) and community models from MakerWorld/Thangs
- **XT60 Adaptation**: Using XT30 mount design for XT60 connector (compatible mounting pattern)
- **GPS Features**: Enables GPS Rescue, Return Home, and position hold in Betaflight
- **Battery Chemistry**: HV batteries (High Voltage LiPo) - 6S 22.2V nominal
- **Flight Time**: Expected 8-12 minutes in cruising flight
- **ESC Firmware**: BlueJay firmware on SpeedyBee AIO
- **Lost Model Recovery**: VIFLY GPS-Mate critical for cruising missions away from home point
- **Control Range**: ExpressLRS provides extended range for exploration flights
- **Custom Parts**: 3D printed TPU mounts for GPS stack (yellow for visibility)
- **Build Duration**: Extended build timeline (172+ days) reflects methodical, careful construction approach
- **Platform Size**: 3.5" wheelbase - small enough for tighter spaces, large enough for stable cruising

---

## Assembly Status Legend

- ✓ **Complete/Available**: Component ready or installed
- ⚠️ **In Progress**: Component partially installed or wired
- ⏳ **Pending**: Component not yet installed
- ❌ **Issue**: Component has problem or unavailable

---

## Maintenance Log

No maintenance actions documented yet (aircraft not yet operational).

---

## Configuration Changes

See `RD-54_Modifications_Log.md` for detailed modification history.
- **MOD-001**: Custom GPS/GPS-Mate stack (November 2025)

---

**Document Version**: 2.0 (Updated November 14, 2025)
**Archivist**: Claude Code, RD-54 SME

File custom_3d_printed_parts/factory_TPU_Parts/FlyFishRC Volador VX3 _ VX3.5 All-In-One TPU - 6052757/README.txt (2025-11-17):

FlyFishRC Volador VX3 / VX3.5 All-In-One TPU by FlyFishRC on Thingiverse: https://www.thingiverse.com/thing:6052757

Summary:
FlyFishRC Volador VX3/VX3.5 TPU Set

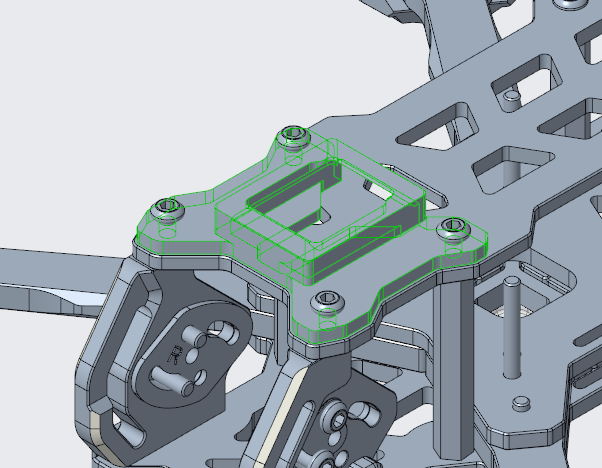
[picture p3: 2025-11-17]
custom_3d_printed_parts/factory_TPU_Parts/FlyFishRC Volador VX3 _ VX3.5 All-In-One TPU - 6052757/images/4c1056a6-c9a1-4f38-9193-2c5e50b23fdf.png

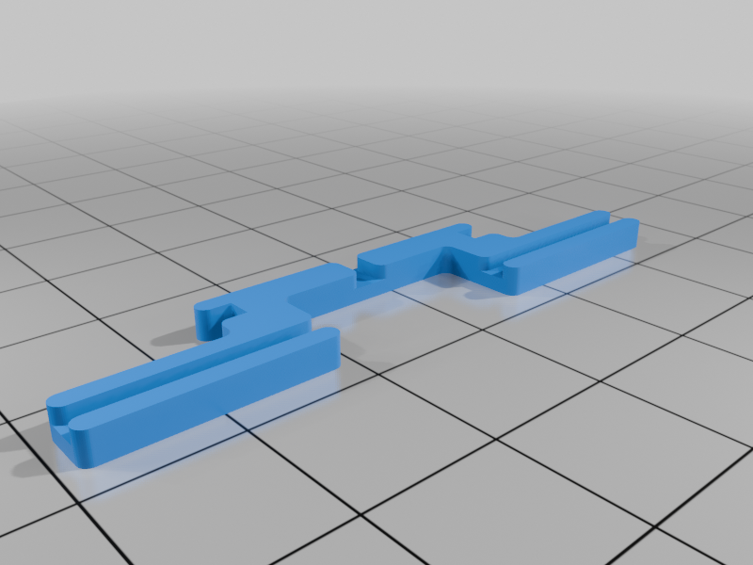
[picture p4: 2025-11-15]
custom_3d_printed_parts/custom_arm_clips/Radiomaster Pocket Built-In Antenna Bracket for EP1 - 6672761/images/92fc9334-223e-4156-b324-81834cc9b5cc.png

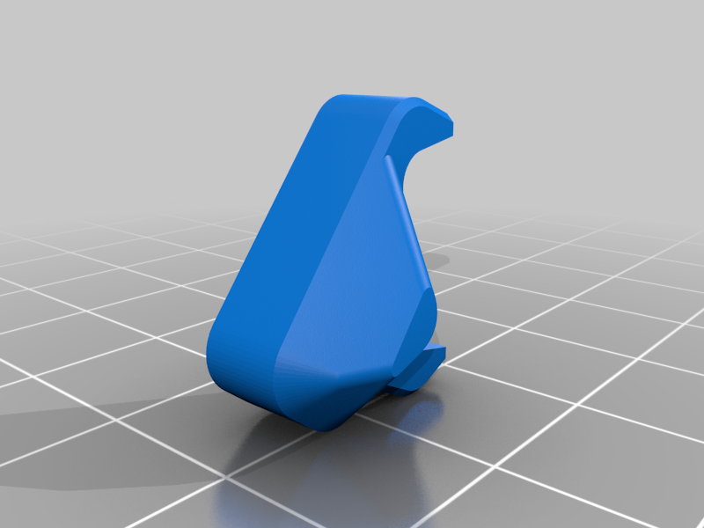
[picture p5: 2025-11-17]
custom_3d_printed_parts/factory_TPU_Parts/FlyFishRC Volador VX3 _ VX3.5 All-In-One TPU - 6052757/images/928535c2-a00a-460f-9ee4-d89cab2d6ddd.png

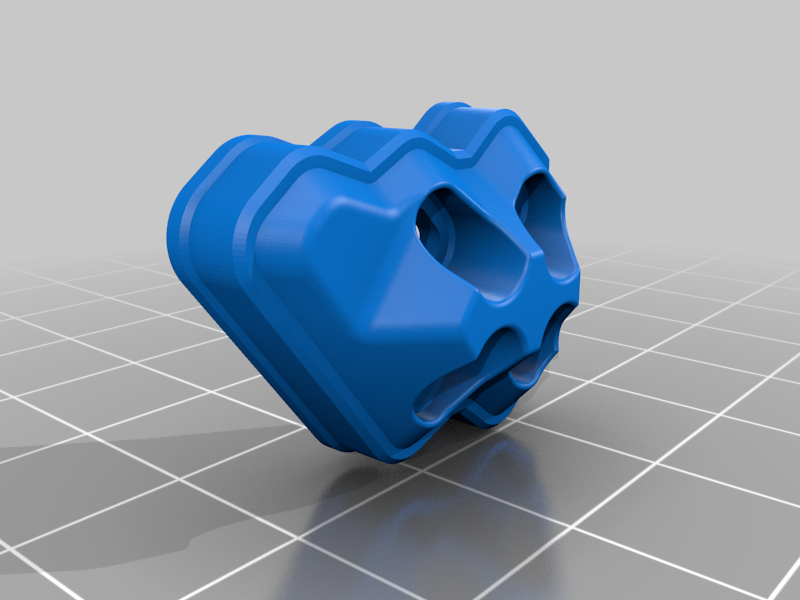
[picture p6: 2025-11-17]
custom_3d_printed_parts/factory_TPU_Parts/FlyFishRC Volador VX3 _ VX3.5 All-In-One TPU - 6052757/images/8a25bf9e-1c5a-46ed-a7ee-430cfe9c74df.png

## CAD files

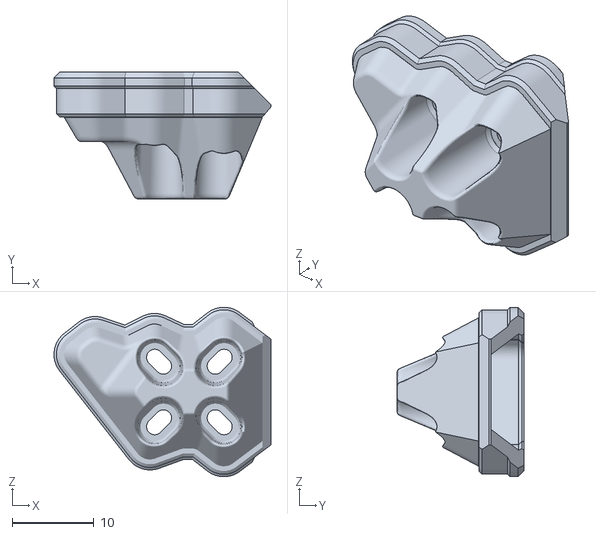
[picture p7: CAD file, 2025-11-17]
custom_3d_printed_parts/Taller Feet/VX3.5-ArmGuard-Tall-Full-R.stl
26.6 x 15.5 x 20.8

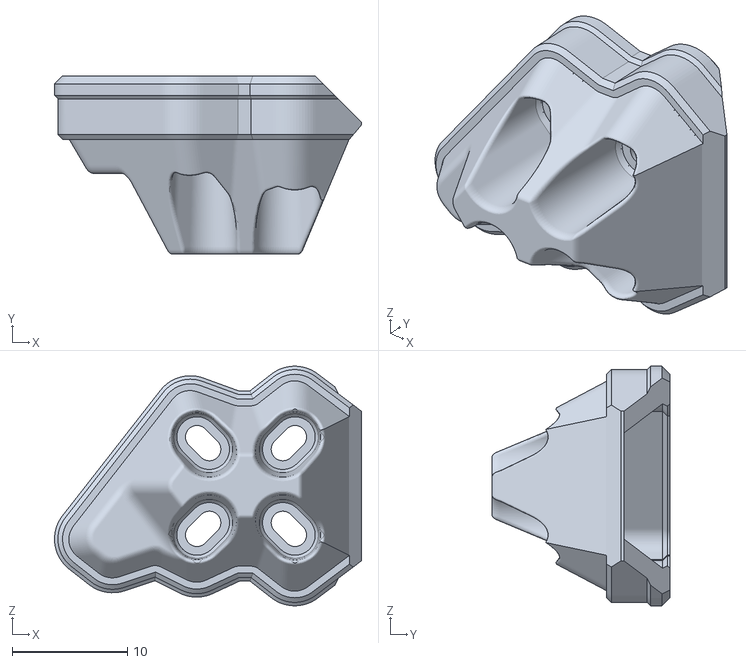
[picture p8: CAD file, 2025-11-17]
custom_3d_printed_parts/Taller Feet/VX3.5-ArmGuard-Tall-Full-L.stl
26.6 x 15.4 x 20.8

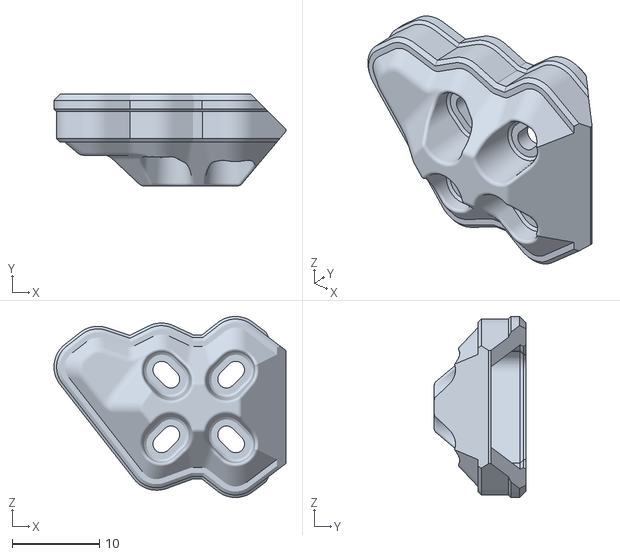
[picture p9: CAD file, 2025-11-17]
custom_3d_printed_parts/factory_TPU_Parts/FlyFishRC Volador VX3 _ VX3.5 All-In-One TPU - 6052757/files/VX3-ArmGuard-Full-R.stl
26.6 x 10.5 x 20.8

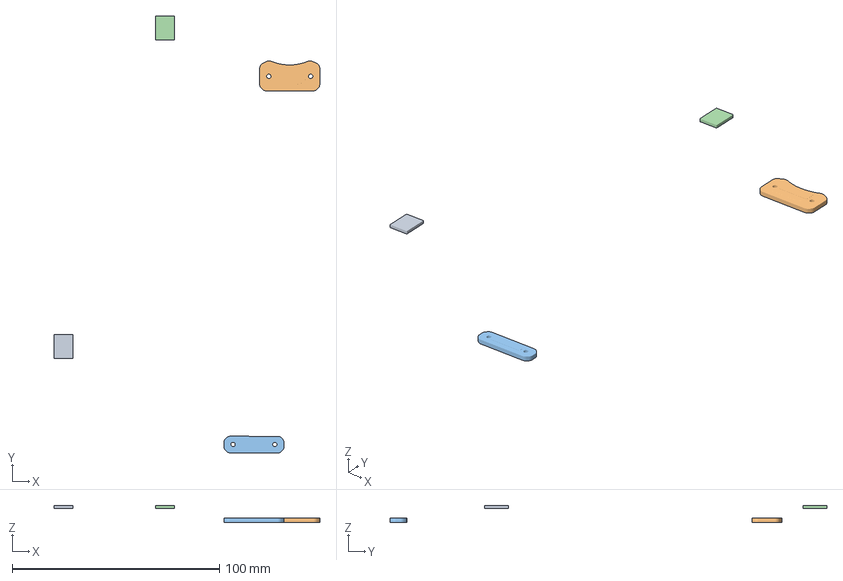
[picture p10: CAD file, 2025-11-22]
custom_3d_printed_parts/BEC-mount/Volador-X3.5-BEC-mount.3mf
128.2 x 210.9 x 8.30 mm
case v1
case v3
mount
Assembly
case v2

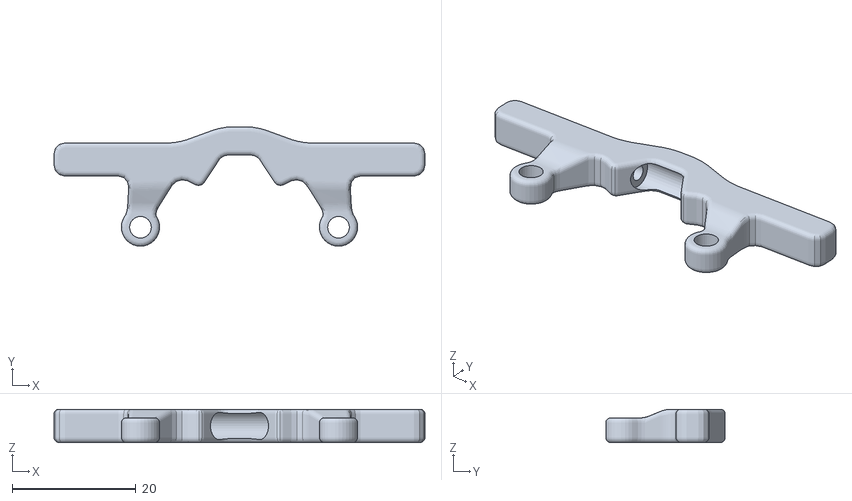
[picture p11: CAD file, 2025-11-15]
custom_3d_printed_parts/custom_arm_clips/AOS 3.5 ELRS antenna mount (Happymodel EP1) - 6327853/files/elrs_antenna_holder_v2.stl
59.9 x 19.3 x 5.40

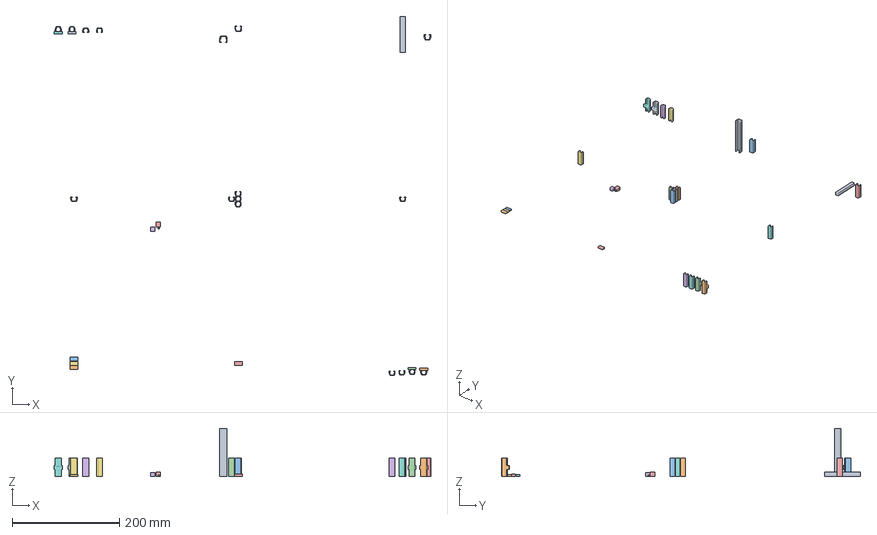
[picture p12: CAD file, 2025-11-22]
custom_3d_printed_parts/custom_arm_clips/volador3.5_arm_clips_final.3mf
703.1 x 670.3 x 90.0 mm
V1
v5cover x 4
V1.1
volador3.5_motor_wires_shield_35mm.stl
v4 x 9
v1.2
Assembly
v1.3
v2
3mm Ref Cube
9mm Ref Cube
8mm Ref Cube
v3
V3

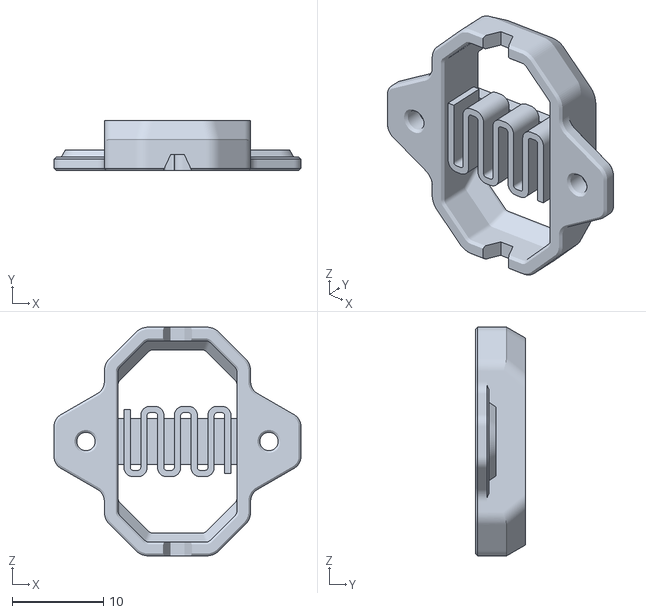
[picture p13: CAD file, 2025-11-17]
custom_3d_printed_parts/factory_TPU_Parts/FlyFishRC Volador VX3 _ VX3.5 All-In-One TPU - 6052757/files/Receiver_Holder.stl
27.0 x 5.50 x 25.0

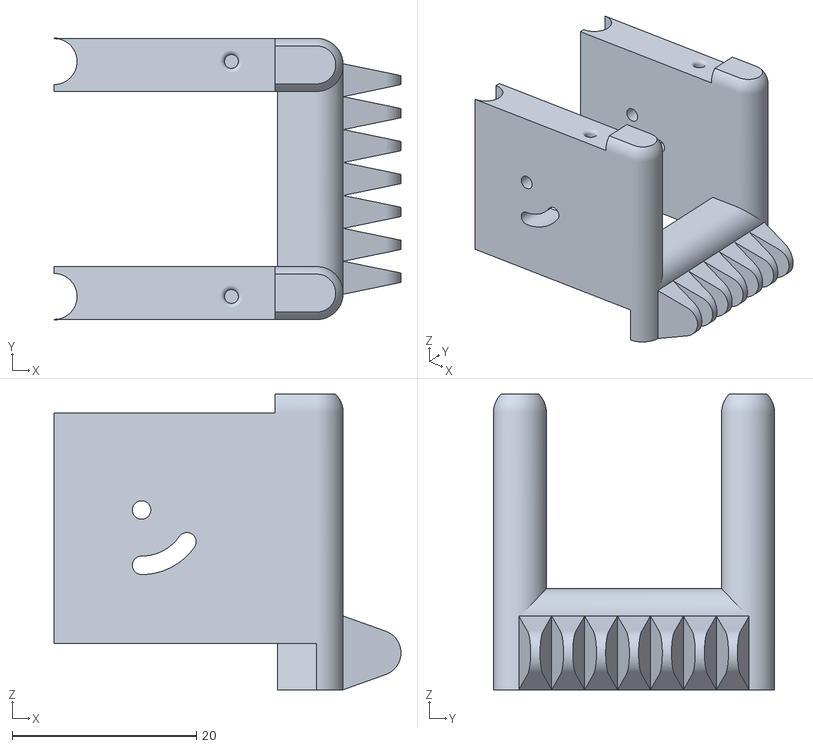
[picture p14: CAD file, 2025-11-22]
custom_3d_printed_parts/front_bumper_camera_mount/cameraBumper.stl
37.6 x 30.5 x 32.1

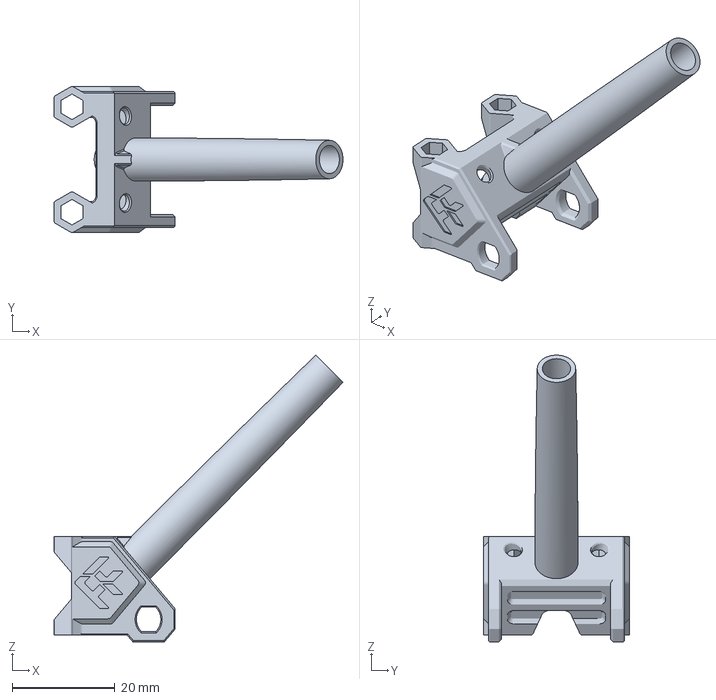
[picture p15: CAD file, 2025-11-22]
custom_3d_printed_parts/HDZERO-Antenna-Mount/valdor3.5_single_VTX_antenna_mount.3mf
56.2 x 28.5 x 55.8 mm

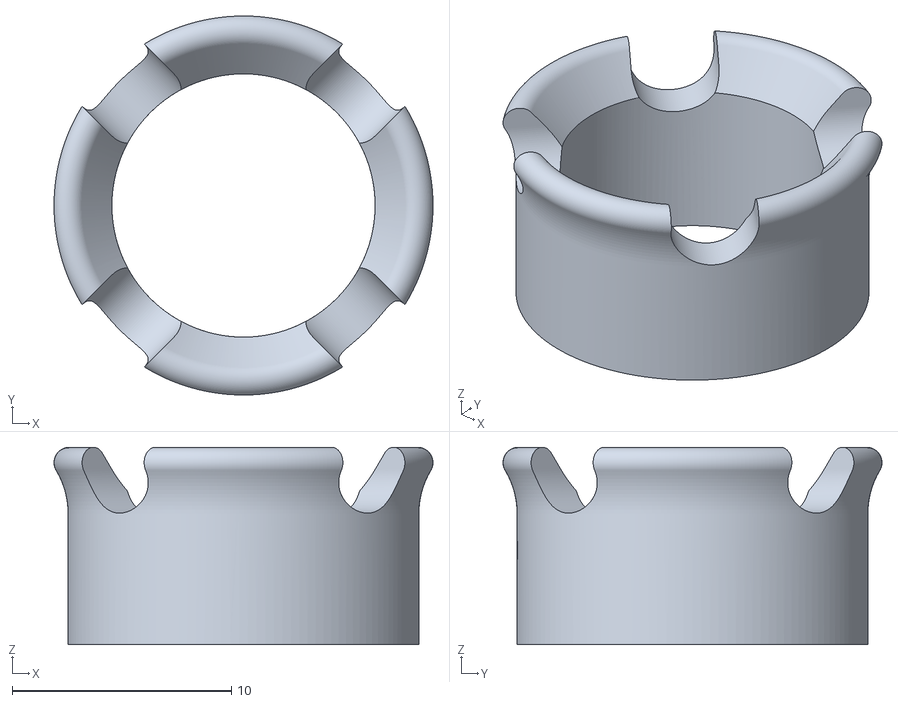
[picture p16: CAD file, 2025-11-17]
custom_3d_printed_parts/RunCam Nano 90 HDZERO/runcam-nano-90-protector.stl
17.3 x 17.3 x 9.00

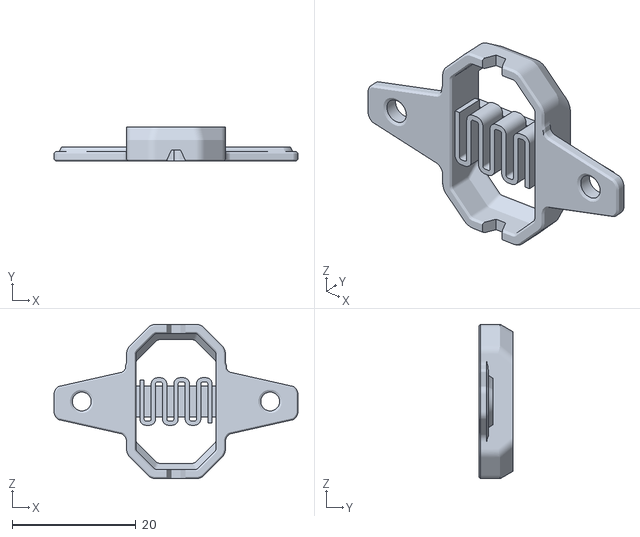
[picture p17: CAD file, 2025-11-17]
custom_3d_printed_parts/RX mount/30.5 mm Receiver Holder (e.g. EP1, FlyFishRC VX3 style) - 7046298/files/Receiver_Holder_edit.stl
39.5 x 5.50 x 25.0

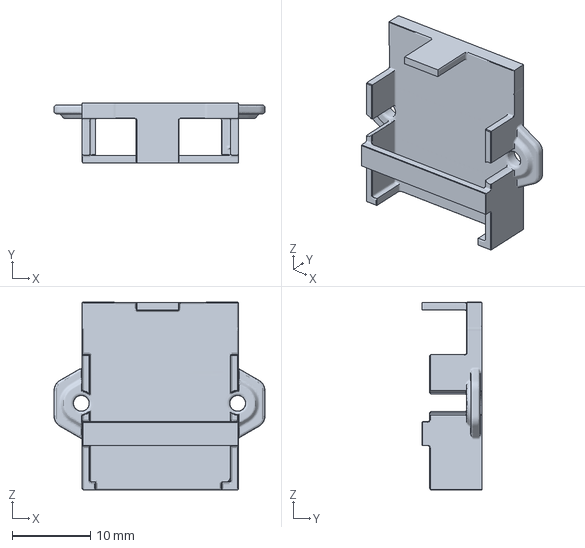
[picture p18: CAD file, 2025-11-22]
custom_3d_printed_parts/RX mount/v6.4_rx_holder.3mf
27.0 x 7.71 x 24.0 mm

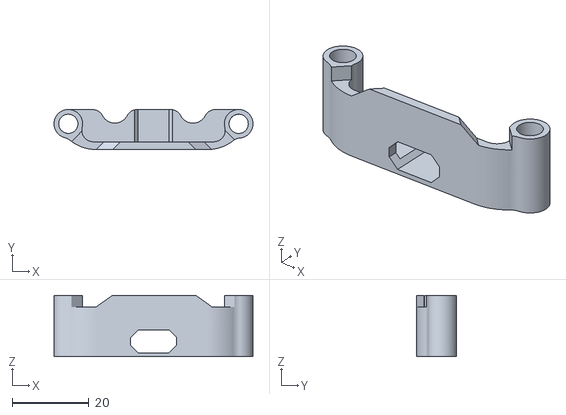
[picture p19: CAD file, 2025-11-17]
custom_3d_printed_parts/stack guards/FlyFishRC Volador VX3 VX3 5 Stack Guards/Stack Guard FC USB Side.stl
51.9 x 10.4 x 16.0

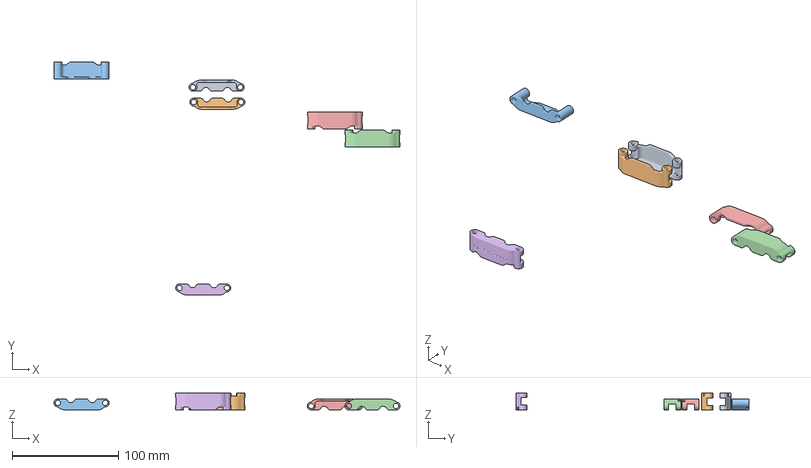
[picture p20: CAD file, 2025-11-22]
custom_3d_printed_parts/stack guards/volador3.5_SpyD_Stack_Guards.3mf
325.7 x 219.5 x 16.0 mm
Stack Guard Nameplate Side.stl x 6

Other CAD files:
custom_3d_printed_parts/factory_TPU_Parts/FlyFishRC Volador VX3 _ VX3.5 All-In-One TPU - 6052757/files/VX3-ArmGuard-Full-L.stl
custom_3d_printed_parts/XT30 Mount Spyd.stl
custom_3d_printed_parts/XT30-mount/Volador+X3.5+-+XT30+Mount.3mf
custom_3d_printed_parts/custom_arm_clips/v4_arm_cover.stl
custom_3d_printed_parts/RX mount/Dual EP1 ELRS RX Moun4t for FLyfishRD Volaror 3.5 V3.stl
custom_3d_printed_parts/RX mount/Dual EP1 ELRS RX Mount for FLyfishRD Volaror 3.5 V1.stl
custom_3d_printed_parts/RX mount/ELRS+TCXO+EP1+DUAL+MOUNT+V1.stl
custom_3d_printed_parts/RX mount/Happymodel_EP1_20x20_holder.stl
custom_3d_printed_parts/RX mount/Happymodel_EP1_plain_holder.stl
custom_3d_printed_parts/custom_arm_clips/Chimera+motor+wires+shield+90mm.stl
custom_3d_printed_parts/custom_arm_clips/Chimera+motor+wiring+shield+90mm.3mf
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

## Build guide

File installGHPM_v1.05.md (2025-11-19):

# GitHub Project Management Setup for Drone Projects v1.05

**Purpose**: This document provides a complete prompt for Claude Code to set up a comprehensive GitHub-based project management system for your drone build project.

**What This Sets Up**:

- GitHub CLI installation and authentication
- Custom issue labels for drone project tracking
- GitHub Project board for visual task management (linked to repository)
- Kanban Board and Milestone Roadmap views
- Milestones for tracking major build goals
- Initial issues for pending work (all assigned to milestones AND project board)
- Documentation in your CLAUDE.md file
- View setup guide for project configuration
- **Mandatory milestone assignment policy**
- **Mandatory project board addition policy**

**Version History**:
- v1.05 (2025-11-19): Added mandatory project board addition requirement (ALL issues must be on project board)
- v1.04 (2025-11-19): Added mandatory milestone assignment requirement (no exceptions)
- v1.03 (2025-11-17): Added project views setup (Kanban Board + Milestone Roadmap)
- v1.02 (2025-11-17): Added project-to-repository linking step
- v1.01 (2025-11-17): Initial release

---

## Prerequisites

Before starting, ensure:

- Your drone project is in a Git repository
- The repository has a GitHub remote configured
- You have a CLAUDE.md file (or are willing to create one)
- You're working on macOS (for Homebrew installation)

---

## The Prompt

Copy the text below and paste it into your Claude Code session:

---

### START OF PROMPT

I want you to set up a GitHub project management system for my drone build project. Please follow these steps:

### Step 1: Install and Configure GitHub CLI

1. Install GitHub CLI via Homebrew: `brew install gh`
2. Authenticate with GitHub: `gh auth login`
3. Request additional scopes for project management: `gh auth refresh -s project,read:project --hostname github.com`

### Step 2: Create Issue Labels

Create the following labels for my repository (replace `OWNER/REPO` with my actual GitHub repo):

**Task Type Labels**:

- `incident` (color: #d73a4a) - Crash reports and damage assessments
- `modification` (color: #0075ca) - Planned or in-progress modifications
- `parts-ordered` (color: #fbca04) - Parts ordered, awaiting delivery
- `pending-install` (color: #f9d0c4) - Parts received, awaiting installation
- `maintenance` (color: #d4c5f9) - Routine maintenance tasks
- `enhancement` (color: #a2eeef) - Improvements and upgrades

**Priority Labels**:

- `priority: critical` (color: #b60205) - Airworthiness/safety critical issues
- `priority: high` (color: #d93f0b) - Important but not safety critical

**Component Labels**:

- `video-system` (color: #c5def5) - FPV video system related
- `radio-system` (color: #bfdadc) - Radio/receiver related

Use the `gh label create` command for each label.

### Step 3: Create GitHub Project Board

1. Create a new project called "[MY DRONE NAME] Project Tracker" for my repository
2. Note the project number for future reference
3. Update the project with description and README:
   ```graphql
   mutation {
     updateProjectV2(input: {
       projectId: "PROJECT_ID"
       shortDescription: "Task tracking and milestone roadmap for [DRONE NAME]"
       readme: "# [DRONE NAME] Project\n\nTrack modifications, incidents, and build progress.\n\n## Views\n- **Kanban Board**: Status-based workflow\n- **Milestone Roadmap**: Timeline view of build goals\n- **All Items**: Complete table view"
     }) {
       projectV2 { id }
     }
   }
   ```
4. **Link the project to the repository** using the GitHub GraphQL API:
   - Get the repository node ID: `gh api graphql -f query='{repository(owner: "OWNER", name: "REPO") {id}}'`
   - Get the project node ID from the project creation output
   - Link them: `gh api graphql -f query='mutation {linkProjectV2ToRepository(input: {projectId: "PROJECT_NODE_ID", repositoryId: "REPO_NODE_ID"}) {repository {name}}}'`

### Step 4: Create Milestones

Create the following milestones using the GitHub API (`gh api`):

1. **Working Video** - FPV video system installed and operational
2. **Working GPS** - GPS system installed, configured, and acquiring satellites
3. **Ready To Fly** - All critical systems operational and airworthy
4. **Maiden Flight** - First successful flight by current operator

**Important**: These milestones will be used for ALL issues. Every issue MUST be assigned to a milestone.

### Step 5: Create Initial Issues

Based on my drone's current status, create GitHub issues for:

- Any missing components (receiver, video system, etc.)
- Pending installations
- Known problems or needed repairs

For each issue:

- Assign appropriate labels
- **⚠️ MANDATORY: Assign to a relevant milestone** (every issue MUST have a milestone, no exceptions)
- Assign to me (the repository owner)
- **⚠️ MANDATORY: Add to the project board** (every issue MUST be on the project board, no exceptions)

**CRITICAL RULES**:
1. If you need to create an issue that doesn't fit any existing milestone, create a new milestone first, then create the issue with that milestone assignment. Never create an issue without a milestone.
2. **IMMEDIATELY after creating each issue**, add it to the project board using the GraphQL API:
   ```bash
   # Get the issue node ID
   ISSUE_ID=$(gh issue view ISSUE_NUMBER --repo OWNER/REPO --json id --jq '.id')

   # Add to project board
   gh api graphql -f query='
   mutation {
     addProjectV2ItemById(input: {
       projectId: "PROJECT_ID"
       contentId: "'$ISSUE_ID'"
     }) {
       item { id }
     }
   }'
   ```
3. **NEVER skip the project board addition step**. All issues must be visible on the project board.

### Step 6: Create Project View Setup Guide

Create a file called `GHPM_View_Setup_Guide.md` that provides step-by-step instructions for configuring project views through the GitHub web interface:

1. **Kanban Board View**: Instructions for creating a Board layout grouped by Status
2. **Milestone Roadmap View**: Instructions for creating a Roadmap layout grouped by Milestone
3. **View Management**: Tips for filters, sorting, and default view settings
4. **Workflow Automation**: Optional auto-archive and auto-add configurations

**Note**: GitHub Projects v2 does not expose view creation via GraphQL API, so views must be configured through the web interface. The guide should be comprehensive enough for quick (2-minute) setup.

### Step 7: Update CLAUDE.md

Add a comprehensive "GitHub Issues & Project Management" section to my CLAUDE.md file that documents:

1. **Dual-Track Documentation System**: Explain that we use both Markdown docs (comprehensive archive) and GitHub Issues (active task tracking)

2. **GitHub Project Structure**: Document the project board number, milestones, column structure, and available views (Kanban Board, Milestone Roadmap)

3. **Issue Label System**: List all labels and their purposes

4. **When to Create GitHub Issues**: Define when issues should be created (crashes, parts orders, modifications, bugs, maintenance)

5. **Issue Creation Workflow**: Step-by-step process for creating and documenting issues
   - **⚠️ CRITICAL**: Include mandatory milestone assignment requirement
   - Document how to create new milestones if needed
   - Emphasize that every issue MUST have a milestone with NO exceptions

6. **Integration Between Issues and Docs**: How to cross-reference between GitHub issues and Markdown documentation

7. **Common gh CLI Commands**: Provide a reference of frequently used commands including:
   - Creating issues with labels, assignee, and milestone
   - Listing issues by label or assignee
   - Updating issues
   - Closing issues
   - Adding issues to project board
   - Listing milestones
   - Creating new milestones

8. **Issue Lifecycle**: Explain the typical flow from creation to completion

9. **Best Practices**: Guidelines for issue titles, bodies, labels, and comments
   - **⚠️ MANDATORY**: Emphasize that milestones are required for every issue

10. **Milestone Assignment Guidelines**: Which types of issues go to which milestones
    - Include instructions for creating new milestones when needed

11. **Project Views**: Document available views and when to use each

Also update the "Future Claude Instances" section to:
- Remind future Claude sessions to check open GitHub issues when starting work
- **Add verification step**: Check that all issues have milestone assignments
- Provide command: `gh issue list --repo OWNER/REPO --json number,title,milestone`

### Step 8: Commit Changes

Create a git commit documenting the GitHub project management setup with an appropriate commit message.

### Step 9: Provide Summary

Give me a summary of:

- What was set up
- Project board number and URL
- Number of labels created
- Number of milestones created
- Number of initial issues created
- **Confirm**: All issues have milestone assignments ✓
- How to access the project in VS Code or GitHub web
- **Reminder**: Configure Kanban Board and Milestone Roadmap views using GHPM_View_Setup_Guide.md (~2 minutes)

### END OF PROMPT

---

## Expected Outcome

After running this prompt, you will have:

✓ GitHub CLI installed and authenticated
✓ Custom issue labels tailored for drone projects
✓ A GitHub Project board with description and README
✓ Project board linked to your repository for better integration
✓ Four milestones tracking major build goals
✓ Initial issues created for your pending work
✓ **All issues assigned to milestones (mandatory policy)**
✓ Complete documentation in CLAUDE.md for future Claude sessions
✓ GHPM_View_Setup_Guide.md for quick view configuration
✓ All changes committed to your repository

**Next Step**: Follow `GHPM_View_Setup_Guide.md` to configure Kanban Board and Milestone Roadmap views (~2 minutes via web interface).

---

## Quick View Setup

After running the automated setup, configure project views:

1. Open your project: `https://github.com/users/OWNER/projects/PROJECT_NUMBER`
2. Follow instructions in `GHPM_View_Setup_Guide.md` to create:
   - **Kanban Board** view (Board layout, grouped by Status)
   - **Milestone Roadmap** view (Roadmap layout, grouped by Milestone)
3. Set Kanban Board as default view
4. Done! Your project now has full kanban + roadmap workflow

**Why Manual Setup?** GitHub Projects v2 API does not expose view creation mutations. Views must be configured through the web UI, but the process is quick and well-documented in the guide.

---

## Customization Options

You can customize the setup by:

1. **Adding/Removing Labels**: Adjust the label list based on your project needs
2. **Changing Milestones**: Modify milestone names/descriptions for your specific goals
3. **Additional Components**: Add component-specific labels (flight-controller, esc, motors, etc.)
4. **Priority Levels**: Add medium/low priority labels if needed
5. **Project Views**: Create additional filtered views (by component, priority, etc.)
6. **Workflow Automation**: Enable auto-archive and auto-add in project settings

---

## Using the System

Once set up, Claude Code will automatically:

- Create GitHub issues when you report crashes, parts orders, or modifications
- Assign issues to you with appropriate labels and milestones
- **Ensure every issue has a milestone assignment (mandatory policy)**
- Update Markdown documentation alongside GitHub issues
- Cross-reference between issues and documentation
- Track progress on the project board

You can access your issues and project board:

- **In VS Code**: GitHub Pull Requests and Issues extension (built-in)
- **On the Web**: <https://github.com/OWNER/REPO/issues> and <https://github.com/users/OWNER/projects/PROJECT_NUMBER>
- **Via CLI**: `gh issue list --repo OWNER/REPO` or `gh project view PROJECT_NUMBER --owner OWNER`

### Recommended Workflow

1. **Daily**: Check Kanban Board view for active tasks
2. **Weekly**: Review Milestone Roadmap to track progress toward goals
3. **On Crash/Issue**: Create GitHub issue + document in Markdown (assign milestone!)
4. **On Completion**: Close issue + update Markdown with results

---

## Milestone Assignment Policy

**⚠️ MANDATORY REQUIREMENT**: Every issue MUST be assigned to a milestone. No exceptions.

**Why This Matters**:
- Milestones provide clear goals and deadlines
- Milestone Roadmap view requires milestone assignments to be useful
- Unassigned issues are invisible on roadmap planning
- Helps prioritize work toward major project goals

**How to Handle Edge Cases**:
- If no existing milestone fits, create a new one first
- Use `gh api repos/OWNER/REPO/milestones -X POST -f title="Name" -f description="Desc"`
- Then assign the new milestone to your issue
- Future Claude instances will enforce this policy automatically

**Verification**:
Check that all issues have milestones:
```bash
gh issue list --repo OWNER/REPO --json number,title,milestone
```

Any issue showing `"milestone": null` needs immediate milestone assignment.

---

## Maintenance

The system is self-maintaining through Claude Code, but you can:

- Review and close completed issues
- Drag issues between columns on Kanban Board
- Update milestone progress and due dates
- Add new labels or milestones as needed
- Create filtered views for specific workflows
- Enable workflow automation for auto-archiving completed items
- **Verify all new issues have milestone assignments**

---

## Support

This project management system was developed for drone build projects. Reference implementations:
- RD-53 "Bandit": <https://github.com/spydmobile/RD53_Bandit>
- RD-54 "Zorro": <https://github.com/spydmobile/rd54_zorro>
- RD-59 "Nazgul": <https://github.com/spydmobile/RD59_Nazgul>

For questions or improvements, refer to the CLAUDE.md file in your repository after setup.

---

**Pro Tip**: After setup and view configuration, ask Claude Code to "provide current status of [YOUR DRONE NAME]" to get a comprehensive status report including GitHub issue tracking, milestone progress, and airworthiness status from both the Kanban Board and Milestone Roadmap perspectives.

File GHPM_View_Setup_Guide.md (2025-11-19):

# GitHub Project Views Setup Guide
# RD-54 Zorro Project Tracker

**Project**: RD-54 Zorro Project Tracker (Project #15)
**Project URL**: https://github.com/users/spydmobile/projects/15
**Setup Time**: ~2 minutes
**Last Updated**: November 19, 2025

---

## Overview

This guide provides step-by-step instructions for configuring project views through the GitHub web interface. GitHub Projects v2 does not expose view creation via GraphQL API, so views must be configured manually.

You will create:
1. **Kanban Board** - Status-based workflow (Board layout)
2. **Milestone Roadmap** - Timeline view of build goals (Roadmap layout)

---

## Prerequisites

- GitHub project created and linked to repository ✓
- Repository issues created ✓
- Milestones created ✓

---

## Step 1: Access Your Project

1. Navigate to: https://github.com/users/spydmobile/projects/15
2. You should see the default "All Items" table view

---

## Step 2: Create Kanban Board View

### 2.1 Create New View

1. Click the **"+"** button next to the current view tabs (top of project)
2. Select **"New view"**
3. Choose **"Board"** layout
4. Name it: **"Kanban Board"**
5. Click **"Create"**

### 2.2 Configure Board Grouping

1. In the Kanban Board view, click **"..."** (view options menu)
2. Select **"Group by"**
3. Choose **"Status"**

The board will now show columns: **Todo**, **In Progress**, **Done**

### 2.3 Configure Board Filters (Optional)

To hide closed issues:

1. Click **"Filter"** at the top
2. Add filter: `is:open`
3. This keeps the board focused on active work

### 2.4 Board Usage

- **Drag issues** between columns to change status
- **Click an issue** to view details and add comments
- **Use labels** for additional categorization
- **Filter by milestone** to see progress toward specific goals

---

## Step 3: Create Milestone Roadmap View

### 3.1 Create New View

1. Click the **"+"** button next to view tabs
2. Select **"New view"**
3. Choose **"Roadmap"** layout
4. Name it: **"Milestone Roadmap"**
5. Click **"Create"**

### 3.2 Configure Roadmap Grouping

1. In the Milestone Roadmap view, click **"..."** (view options menu)
2. Select **"Group by"**
3. Choose **"Milestone"**

The roadmap will now show swim lanes for each milestone:
- Working Video
- Working GPS
- Ready To Fly
- Maiden Flight

### 3.3 Configure Roadmap Timeline

The roadmap will automatically display:
- **Start dates** (issue creation date)
- **Due dates** (milestone due dates, when set)
- **Progress bars** showing completion percentage per milestone

### 3.4 Roadmap Usage

- **Drag issues** horizontally to adjust timelines
- **Drag issues** vertically to reassign milestones
- **Click milestones** to view/edit milestone details
- **Set milestone due dates** for better timeline visualization

---

## Step 4: Set Default View

1. Navigate to your preferred view (Kanban Board recommended)
2. Click **"..."** (view options menu)
3. Select **"Set as default view"**

Now when you open the project, you'll land on your preferred view.

---

## Step 5: Configure Workflow Automation (Optional)

### Auto-Archive Closed Issues

1. Go to project **Settings** (gear icon, top right)
2. Navigate to **"Workflows"** section
3. Enable **"Auto-archive items"**
4. Configure: Archive items when **"Status"** is set to **"Done"**

This automatically removes completed issues from active views while preserving them in the project.

### Auto-Add New Issues

1. In project **Settings** → **"Workflows"**
2. Enable **"Auto-add to project"**
3. Configure: Automatically add issues from **spydmobile/rd54_zorro**
4. Optional: Filter by labels (e.g., only add issues with specific labels)

This automatically adds new repository issues to your project.

---

## Available Views Summary

After completing this guide, you'll have:

| View Name | Layout | Grouped By | Purpose |
|---|---|---|---|
| **All Items** | Table | None | Complete list of all issues with full details |
| **Kanban Board** | Board | Status | Active workflow management (Todo → In Progress → Done) |
| **Milestone Roadmap** | Roadmap | Milestone | Timeline view of build progress toward major goals |

---

## View Selection Guide

**Use Kanban Board when**:
- Working on daily tasks
- Prioritizing what to work on next
- Moving issues through workflow stages
- Quick status updates

**Use Milestone Roadmap when**:
- Planning long-term build goals
- Tracking progress toward major milestones
- Understanding project timeline
- Identifying blockers to airworthiness

**Use All Items when**:
- Searching for specific issues
- Bulk editing multiple issues
- Generating reports
- Reviewing complete project history

---

## Customization Tips

### Creating Additional Views

You can create unlimited custom views:

1. **By Component**: Filter by `video-system` or `radio-system` labels
2. **By Priority**: Filter by `priority: critical` or `priority: high`
3. **By Assignee**: Filter by assignee for multi-operator fleets
4. **By Label**: Create views for `incident`, `modification`, `maintenance`, etc.

### Advanced Filters

Combine filters for powerful views:

- `is:open label:priority:critical` - Open critical issues only
- `is:open milestone:"Working Video"` - Active video system tasks
- `is:closed closed:>2024-11-01` - Recently completed work
- `label:incident` - All crash reports and incidents

### Sorting and Display

- **Sort by**: Priority, creation date, update date, assignee
- **Show/hide fields**: Customize visible columns in table view
- **Field widths**: Resize columns to optimize display

---

## Maintenance

Your project views are now configured! Regular maintenance:

- **Weekly**: Review Kanban Board, move issues through workflow
- **Monthly**: Review Milestone Roadmap, update milestone due dates
- **As needed**: Create filtered views for specific workflows
- **After flight**: Update issues with test results and close completed items

---

## Troubleshooting

**Issues not appearing in project?**
- Check if auto-add workflow is enabled
- Manually add: Open issue → Click "Projects" on right sidebar → Select "RD-54 Zorro Project Tracker"

**Roadmap not showing timeline?**
- Set milestone due dates for timeline visualization
- Check that issues are assigned to milestones

**Board columns not showing?**
- Verify "Group by: Status" is selected
- Check that issues have status field populated

**Can't find a view?**
- Use view tabs at top of project
- Check if view was accidentally deleted (recreate using this guide)

---

## Next Steps

1. ✓ Configure Kanban Board view
2. ✓ Configure Milestone Roadmap view
3. ✓ Set default view
4. ✓ Enable workflow automation (optional)
5. Start using the project!

Open your project: https://github.com/users/spydmobile/projects/15

---

## Reference

- **Project Number**: 15
- **Project ID**: PVT_kwHOABBD-s4BIifE
- **Repository**: spydmobile/rd54_zorro
- **Milestones**: 4 (Working Video, Working GPS, Ready To Fly, Maiden Flight)
- **Initial Issues**: 7 (created November 19, 2025)

For detailed issue management workflows, see `CLAUDE.md` → GitHub Issues & Project Management section.

---

**Document Version**: 1.0
**Created**: November 19, 2025
**RD-54 Archivist**: Claude Code

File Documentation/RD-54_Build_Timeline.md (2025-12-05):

# RD-54 "Zorro" - Build Timeline

**Aircraft Designator**: RD-54 (Code Name: Zorro)
**Operator**: SpyD (Franco Nogarin)
**Last Updated**: November 15, 2025

---

## Project Overview

**Platform**: 3.5" Digital FPV Cruiser
**Primary Mission**: Exploration and cinematic FPV flights with HD digital video
**Build Philosophy**: Reliable mini platform optimized for smooth cruising and GPS-assisted flights
**Key Features**: Walksnail HD digital FPV, GPS Rescue/RTH, ExpressLRS long range, lost model recovery

---

## Timeline

### Phase 1: Planning & Parts Procurement

#### May 17, 2025 - Parts Ordered
**Status**: ✓ Completed

Initial parts order placed for complete build:
- FlyFishRC Volador VX3.5 frame
- SpeedyBee F405 AIO 40A FC/ESC
- Emax ECO II 2004 3000KV motors (x4)
- Gemfan Hurricane 3525-3 props
- Walksnail Moonlight VTX kit
- HappyModel ExpressLRS EP1 receiver
- GEPRC M10-DQ GPS/GNSS module
- 5V buzzer
- 2x GNB 880mAh 6S HV 160C XT30 batteries

**Lead Time**: ~9 days

---

### Phase 2: Initial Build

#### May 26, 2025 - Build Started
**Status**: 🔨 In Progress

Build activities commenced. Initial assembly phase.

**Completed Activities**:
- ✓ Frame assembled
- ✓ FC/ESC stack installed and positioned
- ✓ All 4 motors mounted to frame
- ✓ All 4 motors wired to AIO (completed Nov 14, 2025)
- ✓ Solder pads cleaned with alcohol

**In Progress**:
- ⚠️ VTX/Camera installation (next major task)

**Pending Installation**:
- ⏳ ExpressLRS receiver (EP1 available)
- ⏳ Buzzer
- ⏳ Antenna routing
- ⏳ Wire management
- ⏳ GPS stack (fabricated, wired, will be installed last)
- ⏳ Top plate installation

#### November 2025 - MOD-001: Custom GPS Stack
**Status**: ✓ Completed (ready for installation)

Custom 3D printed TPU GPS/GPS-Mate stack designed and fabricated:
- Yellow TPU modular stack design
- Integrates GEPRC M10-DQ GPS module
- Adds VIFLY GPS-Mate lost-model finder
- Both components wired and ready for installation
- Provides improved GPS elevation for better signal reception

**Rationale**: Lost-model recovery critical for small 3.5" platform. Custom integrated solution more elegant than separate mounts.

#### November 14, 2025 - Motor Wiring Completed
**Status**: ✓ Major Milestone Completed

All 4 motors successfully wired to SpeedyBee AIO:
- Motor soldering completed (4 of 4)
- Solder pads cleaned with alcohol for clean connections
- FC/ESC stack positioned and mounted
- Ready for VTX/Camera installation (next major component)

**Status as of November 14, 2025**: Assembly phase ~70% complete. Core structure complete, all motors wired, FC/ESC mounted. Remaining work: install VTX/Camera, receiver, buzzer, GPS stack (last), wire management, top plate.

#### November 15, 2025 - MOD-002: VTX System Change & Custom Arm Covers
**Status**: ✓ Arm Covers V4 & V5 Completed / ⚠️ VTX Change In Progress

**Custom Arm Covers V4 Completed**:
- Custom 3D printed TPU arm covers designed and fabricated (V0-V4 iteration)
- Remixed from Chimera motor wire shield design (90mm)
- Material: Bambu TPU for AMS on X1C printer
- All 4 arms fitted with V4 design
- Design iterations: V0 (original remix) through V4 (final fit)

**V5 Antenna Clip Development - Completed**:
- Goal: Integrate antenna clips into rear arm covers for EP1 dual T-antennas
- Design approach: Solid block with dual-cylinder negative hole for snap-fit retention
- Iteration process: V1.1/V1.2/V1.3 initial variants → V2.0 winner
- **V2.0 Design Changes**: Bigger body with slot for T-leg (V1.x dual-cylinder approach insufficient)
- Print settings: 0.12mm HQ layer height (improved layer bonding for snap-in/out forces parallel to layers)
- Integration method: Added shim so clip attaches to one side of arm cover only, then fused V2.0 clip geometry
- Retention performance: Strong hold - antennas won't come out unless serious crash
- Final configuration: 2 rear arms with V5 (integrated clips installed), 2 front arms remain V4
- Additional protection planned for underside
- Reference photos:
  - Prototype variants: `Documentation/reference/screengrabs/Screenshot 2025-11-15 at 8.22.51 AM.png`
  - V5 installed: `Documentation/reference/build-images/IMG_5638_arm_cover_V5_bottom.jpg`

**VTX System Technology Change**:
- Original plan: Walksnail Moonlight (digital HD)
- New plan: HDZero Freestyle V2 (digital HD)
- Reason: RD-59 project timeline changed, HDZero Freestyle V2 became available from mapping mission
- Both digital systems, install ramifications similar
- See MOD-002 in Modifications Log for details

#### November 15, 2025 - Custom Parts Batch Fabrication & Installation
**Status**: ⚠️ In Progress (multiple iterations ongoing)

**Parts Printing** (Bambu TPU, 0.12mm HQ for strength and visual quality):
- **HDZero VTX Antenna Holder**: Rear-mounted antenna holder
  - Source: https://makerworld.com/en/models/1769720-flyfishrc-volador-vx3-antenna-mount
  - Designer: FlyFishRC Volador VX3 Antenna Mount (MakerWorld)
- **EP1 RX Holder**: Underside frame-mount for HappyModel EP1 receiver
  - Remixed by operator (removed built-in supports that didn't work well)
  - Original source: TBD
- **XT60 Mount**: Battery connector holder, mounts to rear standoffs beneath top plate for easier LiPo plugging
  - Source: https://makerworld.com/en/models/1203681-volador-vx3-5-xt30-mount
  - Note: Originally designed for XT30, being used for XT60

**Custom Feet - Redesigned for Ground Clearance** (✓ Completed):
- **Design Approach**: Remixed factory arm guards, doubled foot height for 4-5mm additional clearance
  - Source: Factory FlyFishRC Volador VX3/VX3.5 TPU parts (6052757)
  - Design: Screw-mounted style, ~15mm motor mount clearance from ground
- **Initial Configuration**:
  - 2 rear tall feet (screw-on, 15mm clearance)
  - 2 front shorter feet (slip-on, 11-12mm clearance)
  - Result: Uneven stance (1mm front / 20mm rear differential)
- **Final Configuration** (✓ Upgraded and Installed):
  - **All 4 feet now tall and screw-mounted** (~15mm clearance)
  - Even stance achieved - consistent ground clearance all around
  - All screw-mounted for secure attachment
- **Future Plans**:
  - Eventually print smarter front bumper design (+3-5mm for even more balanced stance)
- **Benefit**: Tall feet provide clearance for underside components (antenna mount, RX holder)
- **Reference**: `Documentation/reference/build-images/IMG_5646_tall_rear_foot.jpg`

**EP1 RX Holder - Iterative Development** (✓ V6 Success):
- **Iteration History**: V1-V5 attempts (various approaches didn't work as hoped)
- **V6 Design** (✓ Installed and Working):
  - Base: MakerWorld ELRS EP1 Dual Mount design (`custom_3d_printed_parts/RX mount/ELRS+TCXO+EP1+DUAL+MOUNT+V1.stl`)
  - Modifications: Removed original mount flanges, kept simple holder
  - Added: Factory mounting flanges from FlyFishRC Antenna-Mount.stl
  - File: `custom_3d_printed_parts/RX mount/Dual EP1 ELRS RX Mount for FlyfishRD Volaror 3.5 V6.stl`
  - **Result**: Works as planned, receiver holder successfully mounted to underside frame
- **Lesson**: Persistence pays off - 6 iterations to find working design combination

**Side Panels (Stack Protectors)** (✓ Printed and Installed):
- **Status**: Reprinted with correct "RD-54 ZORRO" designation (original had "RD-54 Bandit" typo)
- **Source**: Remixed from https://than.gs/m/1260429
- **Embossing Quality**: Decent - visible and readable, minor cleanup needed on lettering
- **Installation**: Installed and protecting FC/ESC stack from side impacts
- **Reference**: `Documentation/reference/build-images/IMG_5647_stack_cover.jpg`

**Print Settings Rationale**:
- 0.12mm HQ layer height provides both structural strength and improved visual appearance
- Yellow TPU maintains visibility and crash protection consistency

#### November 20, 2025 - Front Bumper/Camera Mount Design and Installation
**Status**: ✓ Completed

**Custom Design** (Issue #8):
- Base model: MakerWorld 1791670 (Volador VX3.5 19mm Camera Bumper for Bando)
- **Remix rationale**: Original design had critical flaws for bando flying
  - Sawtooth leading edge would catch branches/vegetation
  - Bulky structure added unnecessary weight and snag points
  - Over-engineered ribs provided no benefit in TPU

**Design Improvements**:
- ✅ Smooth, rounded leading edge (no sawtooth - slides past obstacles)
- ✅ Lightweight minimal structure (reduced weight)
- ✅ No snag points (streamlined for tight spaces)
- ✅ Clean bando profile (optimized for close-quarters flying)

**Print Settings**:
- Material: Yellow TPU (consistent with other custom parts)
- Layer height: 0.16mm HQ
- Supports: Tree supports
- Infill: 5% gyroid

**Installation**:
- Mounted to Volador VX3.5 frame
- HDZero Nano 90 camera (19x19mm mount) test fit: ✅ Perfect fit confirmed
- Ready for VTX installation (Issue #1)

**Result**: Functional, lightweight front bumper optimized for bando-style flying. All design flaws from original model corrected.

**References**:
- GitHub Issue #8 (closed)
- Screenshot: Documentation/reference/screengrabs/Screenshot 2025-11-20 at 6.47.06 AM.png

#### November 22, 2025 - EP1 Receiver Assembly and Installation
**Status**: ✓ Completed

**Completed Work** (Issue #3 - partial):
- ✅ New RX holder (v6.4) printed - improved fit over previous versions
- ✅ Leads soldered to EP1 receiver
- ✅ Heat shrink applied to EP1 receiver
- ✅ EP1 mounted in v6.4 RX holder
- ✅ Wired to FC UART6

**EP1 to FC Wiring (UART6)**:
| Wire Color | EP1 Pin | FC Pad | Purpose |
|---|---|---|---|
| Red | 5V | 4V5 | Power |
| Black | GND | G | Ground |
| Blue/Yellow | TX | R6 | Data (TX→RX crossover) |
| Blue | RX | T6 | Data (RX→TX crossover) |

**T-Antenna Installation**:
- ✅ Dual T-antennas installed into V5 arm cover clips

**Remaining for Issue #3**:
- [ ] Bind to transmitter
- [ ] Configure ELRS in Betaflight

**Result**: EP1 receiver fully installed with antennas. Ready for binding and configuration.

#### November 21, 2025 - BEC Protective Enclosure Design and Installation
**Status**: ✓ Completed

**Custom Design** (Issue #9):
- **Challenge**: BEC needs protection but underside mounting was initially rejected due to crash vulnerability
- **Solution**: Two-part protective enclosure to allow underside mounting with full crash protection
- **Location**: Rear underside, mounted to bottom plate with screws

**Design Features**:
- ✅ Two-part screw-together construction (base + lid)
- ✅ BEC fully enclosed and protected from impacts
- ✅ Side wire exits (one opening each side)
- ✅ Wires soldered to BEC at 45° to center on each side for clean side exits
- ✅ Screw mounting to bottom plate for secure attachment

**Print Settings**:
- Material: Red TPU (high visibility, different from yellow custom parts for functional differentiation)
- Layer height: 0.20mm Standard
- Infill: 100% rectilinear (maximum strength for crash protection)
- Supports: Not specified

**BEC Wiring Plan** (documented for VTX installation):
```
flowchart TD
    V[VTX]
    B(Out<br>BEC<br>In)
    V <-->|9V| B
    V <-->|GND| B
    B <-->|VBAT| F{FC AIO}
    B <-->|GND| F
    V <-->|RX| F
    V <-->|TX| F
```

**Physical Connections**:
- **BEC Input** (from FC):
  - FC VBAT pad → BEC BAT (input) - solder connection
  - FC GND pad → BEC G (input) - solder connection
  - BEC S pin: Left floating (LED signal passthrough, not needed for VTX power)
- **BEC Output** (to VTX via JST harness):
  - BEC out → VTX power wire (solder to JST harness power wire)
  - BEC G (output) → VTX GND wire (solder to JST harness GND wire)
  - BEC LED pin: Left floating (extra LED output, not needed)
- **VTX Video Control** (bypass BEC, direct to FC):
  - VTX JST TX wire → FC TX pad (video telemetry via UART)
  - VTX JST RX wire → FC RX pad (video control via UART)

**Enclosure Wire Management**:
- 2 wires IN (from FC): VBAT + GND
- 2 wires OUT (to VTX): 9V + GND
- VTX TX/RX wires route separately to FC (do not pass through BEC enclosure)

**Installation**:
- Enclosure mounted to rear underside bottom plate
- BEC installed inside enclosure
- Wires routed through side exits
- Two-part enclosure secured with screws
- ✅ Test fit confirmed, no clearance issues with battery or other components

**Result**: BEC now protected in crash-resistant enclosure on rear underside. Ready for final wiring to FC and VTX during Issue #1 (VTX installation).

**References**:
- GitHub Issue #9 (will be closed)
- Installed photo: Documentation/reference/build-images/IMG_5666_BEC enclosure.jpg

#### November 19, 2025 - BEC Configuration for HDZero VTX Power
**Status**: ✓ Completed

**BEC Modification**:
- External BEC module (included with SpeedyBee FC) modified from 5V to 9V output
- Soldered 9V jumper per SpeedyBee instructions
- Voltage tested and confirmed: 9V output ✓
- **Purpose**: Provide regulated 9V power for HDZero Freestyle V2 VTX
- **Background**: 6S HV battery (22.2V nominal) exceeds HDZero VTX voltage tolerance

**Mounting Plan**:
- Location: Inline with VTX power cable under top plate
- Custom 3D printed mount planned for clean integration
- Will be mounted and wired during VTX installation (Issue #1)

**Power Path Validated**:
```
6S HV Battery → VBAT → 9V BEC → HDZero VTX
```

**Result**: Critical blocker removed - HDZero VTX installation can now proceed ✓

**References**:
- GitHub Issue #2 (closed)
- SpeedyBee BEC configuration instructions followed

#### November 15, 2025 - HDZero VTX Test Fit & Full Assembly Mockup
**Status**: ✓ Validation Complete

**VTX Test Fit**:
- HDZero Freestyle V2 test fitted to frame
- **Clearance check**: All clearances validated, no interference with side panels or other components
- **Mounting method**: Will use included 3M tape for VTX attachment
- **Camera position**: Front-mounted in aluminum cage (mini bando style for close-quarters flying)
- Camera positioned under GPS stack at front of frame
- **Result**: Fit confirmed, ready for installation

**Full Assembly Mockup**:
- Purpose: Validate custom parts compatibility and plan final assembly
- Components mocked up:
  - GNB 6S battery positioned on top
  - GPS stack placement visualized
  - All yellow TPU custom parts installed
  - Green props mounted for visual reference
- **Validation goals**:
  - Confirm no collisions between custom parts
  - Visualize GPS stack wire routing
  - Plan front bumper redesign (may incorporate adjustable camera mount)
- **Issues discovered**: None yet
- **Next steps**: Front bumper assembly redesign with possible adjustable camera mount integration

**Power Requirement Discovery**:
- **Issue**: 6S HV battery (22.2V nominal) exceeds HDZero VTX voltage tolerance
- **Requirement**: HDZero requires 9V regulated power
- **Solution**: External BEC module (included with SpeedyBee FC package)
  - Specs: Switchable 5V/9V/12V output, current rating TBD
  - **Current Status**: BEC currently configured for 5V output
  - **Required Action**: Modify BEC configuration from 5V to 9V
  - Power path: VBAT → 9V BEC → HDZero VTX
  - Mounting location: TBD
- **Importance**: Discovered during test fit phase - would have caused issues if found during final installation

**EP1 Receiver Preparation Required**:
- **Status**: EP1 receiver available, RX holder V6 installed and ready
- **Required Before Installation**: Apply heat shrink to EP1 receiver
- **Then**: Install heat-shrinked receiver into mounted holder
- **Antennas**: Dual T-antennas ready to mount in V5 arm cover clips after receiver installation

**GPS Wiring Harness Design** (✓ Completed November 19, 2025):
- **Purpose**: Custom harness to connect GPS, GPS-Mate, and FC
- **Approach**: Spliced individual wiring harnesses together
- **Harness Components**:
  - 5-pin JST connector (FC → GPS-Mate): GND (black), TX→RX (white), RX→TX (green), 5V (red), BZ- (yellow)
  - 2 separate I2C solder wires: Drone SDA (white) → GPS-Mate SDA (green), Drone SCL (blue) → GPS-Mate SCL (blue)
- **Status**: Fabrication complete, ready for installation
- **Installation**: Plug 5-pin JST first, then solder I2C wires

**References**:
- VTX test fit: `Documentation/reference/build-images/IMG_5648_test_fit_VTX.jpg`
- Full mockup: `Documentation/reference/build-images/IMG_5649_inspirational_mockup.jpg`

---

### Phase 3: Configuration & Testing

**Status**: ⏳ Pending

Planned activities:
- [ ] Betaflight configuration
- [ ] ExpressLRS binding
- [ ] GPS setup
- [ ] Walksnail VTX configuration
- [ ] Initial power-up testing
- [ ] Bench testing
- [ ] Motor direction verification
- [ ] Pre-flight checks

**Estimated Start**: TBD

---

### Phase 4: First Flight & Tuning

**Status**: ⏳ Pending

Planned activities:
- [ ] Maiden flight
- [ ] Initial PID tuning
- [ ] Rates configuration
- [ ] Performance evaluation
- [ ] Video system testing

**Estimated Start**: TBD

---

## Build Statistics

**Project Duration** (as of Nov 14, 2025):
- Days since parts ordered: 181 days
- Days since build started: 172 days
- Current phase: Initial Build (Assembly Phase)
- Completion: ~70% (estimated)

**Time Allocation**:
- Planning & procurement: 9 days (completed)
- Build in progress: 172+ days (ongoing)
- Configuration: Pending
- Testing: Pending

**Progress Breakdown**:
- Frame/structure: 100%
- Motor mounting: 100%
- Motor wiring: 100% (all 4 complete - Nov 14)
- Electronics installation: 30% (FC/ESC mounted, VTX/RX/buzzer pending)
- Custom modifications: 100% (GPS stack fabricated, ready to install)
- Configuration: 0%
- Testing: 0%

---

## Key Milestones

| Date | Milestone | Status |
|---|---|---|
| May 17, 2025 | Parts ordered | ✓ Completed |
| May 26, 2025 | Build commenced | ✓ Completed |
| May 26 - Nov 2025 | Frame assembled | ✓ Completed |
| May 26 - Nov 2025 | Motors mounted (all 4) | ✓ Completed |
| May 26 - Nov 2025 | FC/ESC installed | ✓ Completed |
| November 2025 | MOD-001: Custom GPS stack fabricated | ✓ Completed |
| November 14, 2025 | Motor wiring completed (all 4) | ✓ Completed |
| November 15, 2025 | Custom arm covers V4 installed (front arms) | ✓ Completed |
| November 15, 2025 | MOD-002: VTX change (Walksnail → HDZero) | ⚠️ In Progress |
| November 15, 2025 | V5 antenna clip prototyping (V1.1/V1.2/V1.3 → V2.0) | ✓ Completed |
| November 15, 2025 | V5 rear arm covers with V2.0 clips installed | ✓ Completed |
| November 15, 2025 | Custom feet redesigned and installed (initial: 2 tall rear, 2 short front) | ✓ Completed |
| November 15, 2025 | Side panels with RD-54 Zorro designation printed and installed | ✓ Completed |
| November 15, 2025 | HDZero VTX test fit and full assembly mockup | ✓ Completed |
| November 15, 2025 | EP1 RX holder V6 printed, installed, and working | ✓ Completed |
| November 15, 2025 | All 4 feet upgraded to tall screw-mounted configuration | ✓ Completed |
| November 15, 2025 | HDZero antenna holder and XT60 mount printed | ✓ Completed |
| November 19, 2025 | GPS/GPS-Mate/FC wiring harness fabricated | ✓ Completed |
| November 19, 2025 | BEC modification (5V → 9V configuration change) | ✓ Completed |
| November 20, 2025 | Front bumper/camera mount designed, printed, and installed | ✓ Completed |
| November 21, 2025 | BEC protective enclosure designed, printed, and installed | ✓ Completed |
| November 22, 2025 | EP1 receiver assembled, mounted, wired to FC UART6, T-antennas in V5 arm clips | ✓ Completed |
| TBD | HDZero antenna holder installation | ⏳ Pending |
| TBD | XT60 mount installation | ⏳ Pending |
| TBD | HDZero VTX/Camera installed | ⏳ Pending |
| TBD | Buzzer installed | ⏳ Pending |
| TBD | GPS stack mounted to aircraft | ⏳ Pending (final component) |
| TBD | Assembly completed | ⏳ Pending |
| TBD | Configuration completed | ⏳ Pending |
| TBD | Maiden flight | ⏳ Pending |
| TBD | Tuning completed | ⏳ Pending |
| TBD | Operational status | ⏳ Pending |

---

## Lessons Learned

### Build Phase Lessons

**Custom Parts Development**:
- 3D printed TPU parts provide flexible, vibration-resistant mounting solutions
- Modular design philosophy allows easy component servicing
- Yellow color improves visibility for small components
- Iterative prototyping approach: Test critical features (snap-fit) independently before integrating into larger parts
- Layer orientation matters for TPU snap-fits: 0.12mm HQ layer height improves bonding when snap forces parallel to layer plane
- 0.12mm HQ also provides superior visual appearance (smoother surfaces) vs standard layer heights
- Prototype multiple variants simultaneously (V1.1/V1.2/V1.3) to accelerate fit testing
- Initial design assumptions may not work (V1.x dual-cylinder approach insufficient for T-antenna geometry)
- V2.0 breakthrough: Bigger body with slot for T-leg provided proper retention vs simple cylindrical holes
- Shim-mounting technique allows clip to attach to one side of arm cover for better integration
- Strong retention achieved: Antennas won't come out unless serious crash (validates V2.0 design)
- Pre-print review catches errors: Side panel typo (RD-54 Bandit vs Zorro) caught before wasting TPU and print time
- Remix approach accelerates development: Remove bad features (built-in supports) from existing designs vs starting from scratch
- Iterative design is normal: EP1 RX holder took V1-V5 attempts before finding working V6 combination
- Persistence validated: V6 RX holder works as planned after 5 failed attempts - don't give up on good ideas
- Hybrid approach works: Combining parts from different sources (MakerWorld holder + factory mounting flanges) can solve fitment issues
- Upgrade mid-build is fine: Switching from uneven stance (2 tall + 2 short feet) to all 4 tall for consistent clearance
- Ground clearance matters: Custom feet doubled height provides 4-5mm clearance for underside components (antenna mounts)
- Mixed mounting approaches: Screw-on (rear) vs slip-on (front) feet - can optimize per location
- Post-print cleanup: Embossed text may need minor cleanup but still readable and functional
- Mock-up validation critical: Full assembly dry-fit validates custom parts compatibility before final installation
- Test fit before commitment: VTX test fit confirms clearances and mounting approach (3M tape)
- Test fit reveals power requirements: HDZero VTX can't run directly from 6S HV battery - discovered before installation
- External BEC solution: 9V BEC (included with FC) solves voltage regulation issue for VTX
- Mini bando style: Front-mounted camera in aluminum cage optimized for close-quarters flying
- Plan ahead: Mockup helps visualize wire routing and identify future redesigns (front bumper with adjustable camera mount)
- Critical analysis of base models: Evaluate for functional flaws, not just aesthetics (Nov 20, 2025)
- Sawtooth edges are dangerous: Smooth, rounded leading edges slide past branches instead of catching them
- Weight matters on small platforms: Remove unnecessary bulk and over-engineering from remix designs
- Snag points defeat bando purpose: Streamlined surfaces essential for tight-space flying
- 0.16mm HQ with tree supports: Good balance of detail and print speed for larger structural parts
- 5% gyroid infill sufficient for TPU bumpers: Flexibility comes from material, not infill percentage
- Function over form in remixes: Simplifying "silly" designs often improves both aesthetics AND performance
- Custom wiring harnesses: GPS/GPS-Mate/FC integration requires custom splice harness with JST connectors
- Harness fabrication success: 5-pin JST + 2 I2C solder wires approach allows clean, modular connection (Nov 19, 2025)
- Wire color documentation critical: Recording wire colors during fabrication prevents confusion during installation
- Installation sequence matters: Plug JST first, then solder I2C wires for easiest access
- BEC voltage configuration: Always test output voltage with multimeter after modification - critical for component safety (Nov 19, 2025)
- Power planning ahead: Identifying voltage requirements during test fit phase prevents last-minute scrambles
- SpeedyBee BEC: Jumper-based voltage selection (5V/9V/12V) provides flexibility for different component requirements
- Custom BEC mounting: Planning inline installation with VTX power improves wire management and serviceability
- Clearance calculations critical: VTX bay had 19mm clearance, VTX (15mm) + BEC (6mm) = 21mm needed - 2mm short (Nov 21, 2025)
- Alternative mounting exploration: Test multiple locations (VTX top, camera back, underside) before committing to design
- Protective enclosures solve vulnerability: Underside mounting viable when component fully enclosed in crash-resistant housing
- 100% infill for protection: Maximum strength TPU enclosures (100% rectilinear infill) provide crash protection for vulnerable components
- Two-part enclosures provide serviceability: Screw-together design allows access to enclosed component without destroying mount
- Color coding for function: Red TPU for protective enclosures vs yellow for general parts - visual differentiation aids identification
- Wire exit planning: Soldering component leads at 45° to center on each side facilitates clean side-exit wire routing
- BEC S pin can float: LED signal passthrough pin not needed for pure power regulation applications
- Rear underside location works: Near battery connector = shorter VBAT wire run, reasonable distance to VTX

**Component Sourcing**:
- Original ExpressLRS EP1 diverted to other aircraft mid-build
- Having second EP1 available resolved receiver shortage
- Planning for spare critical components valuable for multi-aircraft operation

**Build Approach**:
- Methodical 172-day build timeline reflects quality-over-speed philosophy
- Taking time to design custom solutions (GPS stack) better than rushing with off-the-shelf compromises
- Extended timeline allows for thoughtful engineering decisions

---

## Future Activities

### Immediate (Next Steps)

**Updated November 15, 2025**:
- [x] Complete motor wiring (all 4 motors soldered - Nov 14, 2025)
- [x] Design and fabricate custom arm covers V4 for front arms (Nov 15, 2025)
- [x] Prototype V5 antenna clips (V1.1/V1.2/V1.3 → V2.0 winner - Nov 15, 2025)
- [x] Test snap-fit retention with actual EP1 T-antennas (V2.0 confirmed strong hold - Nov 15, 2025)
- [x] Integrate V2.0 clip design into V5 arm cover geometry (shim-mounted to one side - Nov 15, 2025)
- [x] Print and install V5 rear arm covers with integrated V2.0 clips (0.12mm HQ - Nov 15, 2025)
- [x] Design and print custom feet with doubled height for ground clearance (Nov 15, 2025)
- [x] Install custom feet (2 rear tall, 2 front shorter - uneven stance for now) (Nov 15, 2025)
- [x] Print and install side panels with correct RD-54 Zorro designation (Nov 15, 2025)
- [x] Test fit HDZero VTX and validate clearances (Nov 15, 2025)
- [x] Full assembly mockup to validate custom parts compatibility (Nov 15, 2025)
- [x] Iterate EP1 RX holder design (V1-V6, V6 successful - Nov 15, 2025)
- [x] Install EP1 RX holder V6 to underside frame (works as planned - Nov 15, 2025)
- [x] Print and install 2 more tall feet to replace front (all 4 now tall screw-mounted - Nov 15, 2025)
- [x] Print HDZero antenna holder and XT60 mount (0.12mm HQ TPU - Nov 15, 2025)
- [x] Design GPS/GPS-Mate/FC custom wiring harness (splicing JST connectors - Nov 15, 2025)
- [x] Fabricate GPS wiring harness (splice GPS, GPS-Mate, FC connections - Nov 19, 2025)
- [ ] Modify BEC from 5V to 9V configuration
- [ ] Determine 9V BEC mounting location and install
- [ ] Apply heat shrink to EP1 receiver
- [ ] Install heat-shrinked EP1 receiver into mounted holder
- [ ] Mount and route dual T-antennas to rear arm V5 clips
- [ ] Install HDZero antenna holder to rear mount
- [ ] Wire and install 9V BEC (VBAT → 9V BEC → HDZero VTX)
- [ ] Install HDZero Freestyle V2 VTX/Camera system with 9V power (see MOD-002)
- [ ] Install XT60 mount to rear standoffs beneath top plate
- [ ] Install 5V buzzer
- [ ] Eventually design/print improved front bumper (+3-5mm for even more balanced stance)
- [ ] Cleanup embossed lettering on side panels
- [ ] Wire management and cleanup
- [ ] Mount GPS/GPS-Mate stack to frame (planned as final component)
- [ ] Install top plate

### Short Term (Pre-flight)
- [ ] Initial Betaflight configuration
  - [ ] Motor direction verification
  - [ ] Receiver binding (ExpressLRS)
  - [ ] GPS configuration
  - [ ] Walksnail VTX setup
  - [ ] Buzzer testing
- [ ] Bench testing
  - [ ] Power-up tests
  - [ ] Failsafe configuration
  - [ ] Arming tests
- [ ] Pre-flight safety checks

### Medium Term (Initial Flight Operations)
- [ ] Maiden flight (LOS hover test)
- [ ] Initial PID tuning
- [ ] Rates configuration
- [ ] FPV system validation
- [ ] GPS-Mate functionality test
- [ ] Performance evaluation

### Long Term (Cruiser Operations)
- [ ] Optimize for smooth cruising flight
  - [ ] Tune rates for cinematic flying (smooth, not aggressive)
  - [ ] Optimize PID for stability (minimize oscillations in video)
  - [ ] Test GPS Rescue and Return Home functionality
- [ ] Extended range testing
  - [ ] Test ExpressLRS range with GPS failsafes
  - [ ] Validate GPS-Mate recovery beacon effectiveness
- [ ] Video quality optimization
  - [ ] Walksnail recording settings for best quality
  - [ ] Test different cruising speeds for stable footage
  - [ ] Vibration reduction if needed
- [ ] Explore interesting locations
  - [ ] Identify cruising spots (parks, trails, scenic areas)
  - [ ] Build exploration flight repertoire
  - [ ] Capture cinematic HD footage

---

## Notes

**Build Duration Context**:
Extended build timeline (172+ days) suggests this is a careful, methodical build process rather than rushed construction. Quality over speed approach.

**Platform Evolution**:
Originally planned as 3.5" freestyle platform. Mission refined to **Digital FPV Cruiser** - optimized for smooth exploration flights with HD digital video capture via Walksnail Moonlight. GPS stack (MOD-001) enables GPS Rescue, Return Home, and lost model recovery for extended cruising missions.

**ArduPilot Mapping Platform**:
Considered converting RD-54 to autonomous mapping platform (see `Documentation/reference/ardupilot-mapping-drone-project.md`), but 3.5" size and limited flight time (~5-10 min with camera payload) make it unsuitable for practical mapping work. Decision: Keep RD-54 as Betaflight digital FPV cruiser. Future dedicated mapping platform would be 5"+ with H7 FC and larger batteries.

---

**Document Version**: 2.0 (Updated November 14, 2025)
**Archivist**: Claude Code, RD-54 SME

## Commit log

2025-11-15 Refactor code structure for improved readability and maintainability
    [Chimera+motor+wires+shield+90mm.stl, Chimera+motor+wiring+shield+90mm.3mf, Radiomaster_Pocket_EP1_Antenna_Bracket.stl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]
2025-11-17 ✓ Documented: RX Holder Success & Feet Upgrade (November 15, 2025)
    EP1 RX Holder - V6 SUCCESS
    - Journey: V1-V5 iterations unsuccessful
    - V6 Design: Hybrid approach worked
    - Base: MakerWorld ELRS EP1 Dual Mount holder
    - Added: Factory FlyFishRC mounting flanges
    - Result: ✓ Installed to underside frame and works as planned
    - Lesson: Persistence pays off - 6 iterations to find working combination
    Custom Feet - All 4 Now Tall
    - Initial config: 2 rear tall (15mm) + 2 front short (11-12mm) = uneven stance
    - Upgrade: Printed and installed 2 more tall feet
    - Final config: ✓ All 4 feet tall and screw-mounted at ~15mm clearance
    - Benefit: Even stance, consistent gr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
    [Antenna-Mount.stl, Dual EP1 ELRS RX Moun4t for FLyfishRD Volaror 3.5 V3.stl, Dual EP1 ELRS RX Mount for FLyfishRD Volaror 3.5 V1.stl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]
2025-11-17 Update RD-54 documentation: mark HDZero antenna holder and XT60 mount as printed, modify BEC configuration details, and outline EP1 receiver preparation steps.
2025-11-19 Implement GitHub Project Management system for RD-54 Zorro
    Setup comprehensive GitHub-based task tracking and milestone management:
    **Project Infrastructure**:
    - Created RD-54 Zorro Project Tracker (Project #15)
    - Configured custom issue labels for drone build tracking
    - Created 4 milestones: Working Video, Working GPS, Ready To Fly, Maiden Flight
    - Linked project to repository for seamless integration
    **Initial Issues Created** (7 total):
    - #1: Install HDZero Freestyle V2 VTX/Camera System
    - #2: Modify BEC from 5V to 9V for HDZero VTX
    - #3: Install ExpressLRS EP1 Receiver and Antennas
    - #4: Install GPS/GPS-Mate Stack (harness completed Nov 19)
    - #5: Install HDZero Antenna Holder
    - #6: Ins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
2025-11-19 Close Issue #7: External buzzer not needed, GPS-Mate provides integrated buzzer
    GPS-Mate wiring harness includes BZ- (yellow wire) connected to FC buzzer pads.
    GPS-Mate's built-in buzzer provides all buzzer functionality:
    - Arming/disarming alerts
    - Battery voltage warnings
    - Lost model beacon
    - Other Betaflight buzzer modes
    Updated documentation:
    - RD-54_AsBuilt_Parts_List.md: Buzzer status changed to integrated via GPS-Mate
    - RD-54_Modifications_Log.md (MOD-001): Added buzzer integration details
    - Removed buzzer from pending installations list
    GitHub Issue #7 closed with explanation.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
2025-11-19 Enforce mandatory milestone assignment for all GitHub issues
    **CRITICAL POLICY**: Every issue MUST be assigned to a milestone with no exceptions.
    Updated CLAUDE.md with mandatory milestone requirement in multiple sections:
    - When to Create GitHub Issues: Added critical rule
    - Issue Creation Workflow: Added mandatory requirement with instructions
    - Best Practices > Milestones: Added mandatory policy
    - Future Claude Instances: Added verification step
    If no appropriate milestone exists, create one before creating the issue.
    Never create an issue without a milestone assignment.
    Current status: All 6 open issues have milestone assignments ✓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
2025-11-19 Complete Issue #2: BEC modified to 9V for HDZero VTX power
    **Modification Complete** (November 19, 2025):
    - Soldered 9V jumper per SpeedyBee instructions
    - Voltage tested and confirmed: 9V output ✓
    - Mounting location determined: Inline with VTX power cable under top plate
    - Custom 3D printed mount planned for integration
    **Power Path Validated**:
    6S HV Battery → VBAT → 9V BEC → HDZero VTX
    **Critical Blocker Removed**: HDZero VTX installation can now proceed (Issue #1)
    **Documentation Updated**:
    - RD-54_AsBuilt_Parts_List.md: Updated BEC status, removed blocker
    - RD-54_Build_Timeline.md: Added November 19 entry, updated milestones
    - Lessons learned: Voltage testing, power planning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
2025-11-19 Add mandatory project board integration to issue creation workflow
    **Critical Workflow Fix**: Issues must be added to project board immediately after creation.
    **Problem**: Issues #8 and #9 were created but not automatically added to the project board, requiring manual addition by operator.
    **Solution**: Updated CLAUDE.md Issue Creation Workflow with mandatory step:
    - After creating issue, immediately get issue node ID
    - Use GraphQL mutation to add issue to project board
    - Project ID: PVT_kwHOABBD-s4BIifE
    - Never create an issue without adding it to the project
    **Updated Section**: Issue Creation Workflow (Step 1)
    - Added CRITICAL requirement with code example
    - Documented project board i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
2025-11-19 CRITICAL FIX: Enforce mandatory project board addition for ALL issues
    **Problem**: Issues #1, #3, #4, #5, #6 were created but NOT added to project board, making them invisible on Kanban Board and Milestone Roadmap. This defeats the entire purpose of the project management system.
    **Root Cause**: Documentation did not emphasize that EVERY issue must be added to project board immediately after creation.
    **Immediate Fix**:
    - Added ALL 7 open issues to project board (Issues #1, #3, #4, #5, #6, #8, #9)
    - All issues now visible at https://github.com/users/spydmobile/projects/15
    **Documentation Updates**:
    **CLAUDE.md**:
    - Added second CRITICAL RULE: Every issue MUST be added to project board
    -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
2025-11-19 Document BEC power specifications and HDZero VTX requirements
    **Power Budget Verified** (November 19, 2025):
    HDZero Freestyle V2 VTX power requirements:
    - Max consumption: 15W
    - At 9V: 1.67A minimum required
    SpeedyBee external BEC specifications:
    - Output: 9V @ 2A
    - Headroom: 0.33A (330mA) above VTX requirement
    **Status**: ✅ BEC adequately rated for HDZero VTX
    - RD-54_AsBuilt_Parts_List.md: Added BEC current rating (2A @ 9V)
    - Issue #1: Added power requirements verification comment
    **Source**: HDZero Freestyle V2 documentation
    This is critical information for power system validation before VTX installation.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
2025-11-22 Complete Issue #8 and #9: Front bumper and BEC enclosure installed
    Issue #8 - Front Bumper/Camera Mount:
    - Remixed MakerWorld 1791670 to fix design flaws for bando flying
    - Removed sawtooth leading edge (catch hazard), reduced weight, eliminated snag points
    - Yellow TPU, 0.16mm HQ, tree supports, 5% gyroid infill
    - HDZero Nano 90 camera (19mm mount) test fit confirmed
    - Ready for VTX installation
    Issue #9 - BEC Protective Enclosure:
    - Two-part screw-together enclosure for rear underside mounting
    - Red TPU, 0.20mm Standard, 100% rectilinear infill for crash protection
    - BEC fully enclosed with side wire exits
    - Wires soldered at 45° to center on each side for clean routing
    - Clearance calcu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
    [Volador+VX35+Walksnail+Camera+Bumper.3mf, Volador-X3.5-BEC-mount.3mf, Zorro_Camera_Bumper.3mf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]
2025-11-22 Add all remaining 3D design files and reference images
    3D Design Files Added:
    - RX mount iterations (v6.3, v6.4) - final receiver holder designs
    - Taller feet final design (volador3.5_taller_feet_spyd.3mf)
    - XT30 mount final design (XT30 Mount Spyd.stl)
    - Custom arm clips final design (volador3.5_arm_clips_final.3mf)
    - Stack guards final design (volador3.5_SpyD_Stack_Guards.3mf)
    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
    [XT30 Mount Spyd.stl, v6.4_rx_holder.3mf, valdor3.5_single_VTX_antenna_mount.3mf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]
